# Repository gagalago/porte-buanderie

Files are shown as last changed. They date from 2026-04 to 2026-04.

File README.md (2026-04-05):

# Porte-etagere cuisine-buanderie

Conception d'une porte epaisse avec etageres integrees entre la cuisine et la buanderie,
montee sur un mecanisme 4-bar linkage (bras articules).

## Le probleme

L'ouverture fait 870mm de large. La porte fait 355mm d'epaisseur (pour les etageres).
La diagonale de la porte (940mm) depasse l'ouverture de 70mm, ce qui empeche un pivot
classique de fonctionner : le coin de la porte heurte le mur en pivotant.

## La solution

Un mecanisme a **4 barres articulees** (4-bar linkage) avec :
- 2 bras rigides reliant le mur droit (cote charnieres) a la porte
- 2 pattes qui sortent de la face arriere (buanderie) de la porte
- Le mecanisme combine translation + rotation, evitant la collision diagonale

La porte est **trapezoidale** (plus etroite cote buanderie) et encadree par des
**cadres de 25mm** de chaque cote, ce qui reduit les dimensions effectives.

## Dimensions cles

| Element | Valeur |
|---|---|
| Ouverture | 870mm |
| Mur gauche (trailing) | 355mm d'epaisseur |
| Mur droit (charnieres) | 425mm d'epaisseur |
| Espace derriere mur droit | 380mm (frigo juste derriere) |
| Marche cuisine-buanderie | 190mm |
| Hauteur porte | ~2040mm |

## Solution retenue

| Parametre | Valeur |
|---|---|
| Porte (cote cuisine) | 820 x 355mm |
| Forme | Trapeze, taper 60mm chaque coin buanderie |
| Face buanderie (etageres) | 700mm |
| Cadres | 25mm chaque cote (symetrique) |
| Pivot A (mur) | x=1238, y=428 |
| Pivot B (mur) | x=1188, y=532 |
| Patte a | 95mm, a x=563 sur la porte |
| Patte b | 188mm, a x=743 sur la porte |
| Bras 1 | 675mm |
| Bras 2 | 446mm |
| Rotation | ~91 degres |
| Clearance | ~14-24mm (selon resolution de simulation) |

## Structure du projet

```
porte-buanderie/
  calculs/
    optimisation_documentee.py  # Script principal: parametres + optimiseur
    animate_resultat.py         # Generation d'animation GIF (matplotlib)
    requirements.txt            # numpy, scipy, matplotlib, svgwrite, Pillow
  dessins/
    generate_plans.py           # Generation de plans SVG cotes
  freecad/
    porte_animable.py           # Genere un FCStd avec 21 positions
    live_animation.py           # Animation live via socket FreeCAD (WIP)
  exports/
    RESULTAT_animation.gif      # Animation du mecanisme
    plan_vue_dessus.svg         # Plan cote (vue de dessus)
    plan_porte_detail.svg       # Detail porte + etageres
    porte_animable.FCStd        # Modele 3D FreeCAD (21 positions groupees)
    frames_resultat/            # Frames PNG de l'animation
```

## Lancer l'optimisation

```bash
cd porte-buanderie
python3 -m venv .venv && source .venv/bin/activate
pip install -r calculs/requirements.txt
python3 calculs/optimisation_documentee.py
```

Modifier les parametres en haut de `optimisation_documentee.py` puis relancer.

## Generer l'animation GIF

Apres optimisation, mettre a jour les parametres dans `animate_resultat.py` puis :
```bash
python3 calculs/animate_resultat.py
# -> exports/RESULTAT_animation.gif
```

## Systeme de coordonnees

Vue de dessus, oriente comme depuis la cuisine :
- **X** : gauche (0) a droite (870)
- **Y** : cuisine (0) vers buanderie (positif)
- Mur gauche = cote trailing (x < 0), 355mm d'epaisseur
- Mur droit = cote charnieres (x > 870), 425mm d'epaisseur

## Prochaines etapes

- [ ] Valider les mesures sur place
- [ ] Animation FreeCAD live (socket server crash a resoudre)
- [ ] Plans techniques detailles des charnieres
- [ ] Choix materiaux (porte, bras, axes, roulements)
- [ ] Conception des roulettes (arc au sol buanderie)
- [ ] Prototype carton echelle 1:1
- [ ] Construction

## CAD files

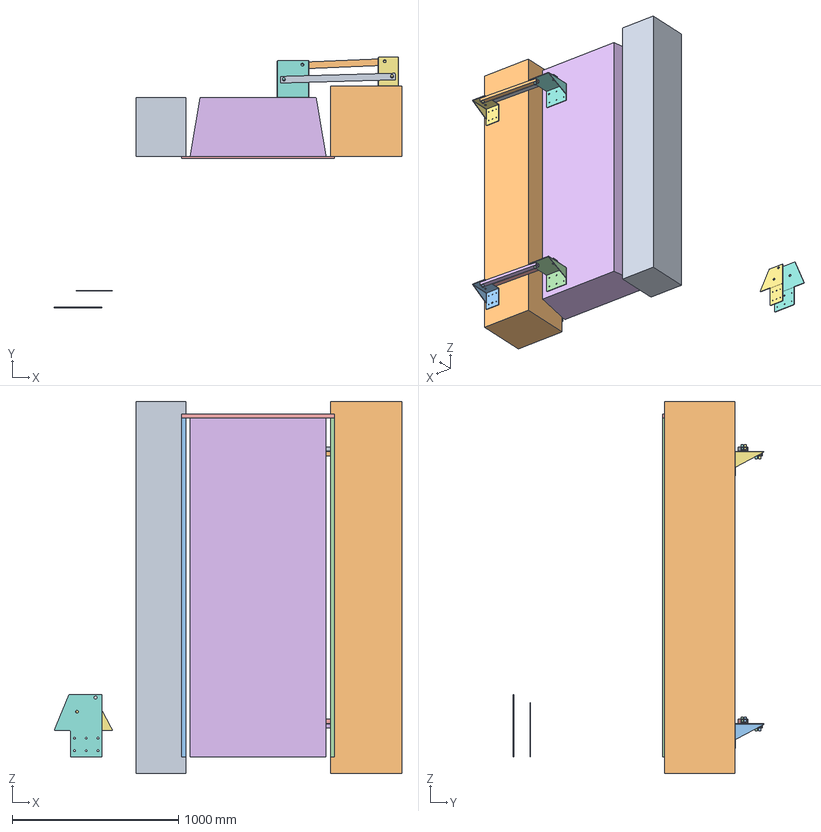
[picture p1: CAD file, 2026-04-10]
exports/assembly_porte.FCStd
2092.6 x 1509.1 x 2240.0 mm
MurGauche
MurDroit
CadreGauche
CadreDroit
CadreHaut
Porte
PlatMur_H
PlatPorte_H
Bras1_H
Bras2_H
PlatMur_B
PlatPorte_B
Bras1_B
Bras2_B
Patron_Plan_Patron_Murale
Patron_Plan_Patron_Porte

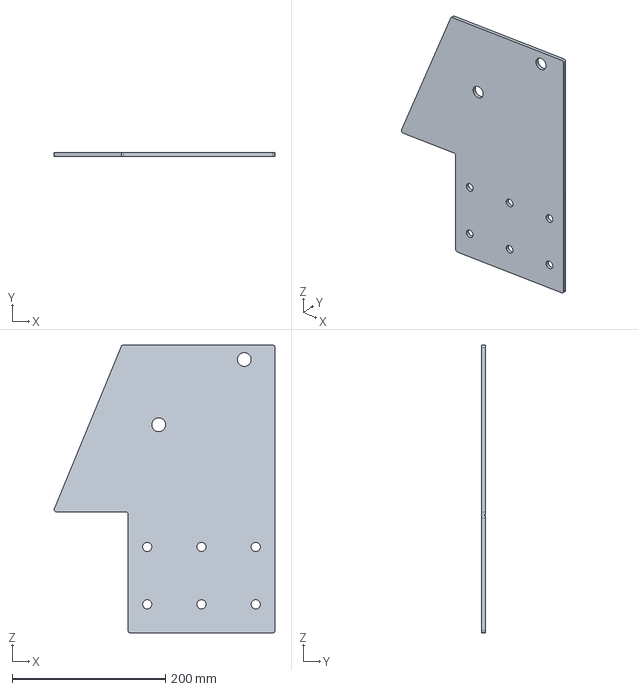
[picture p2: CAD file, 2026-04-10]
exports/patron_laser_porte.step
288.5 x 5.00 x 376.4 mm

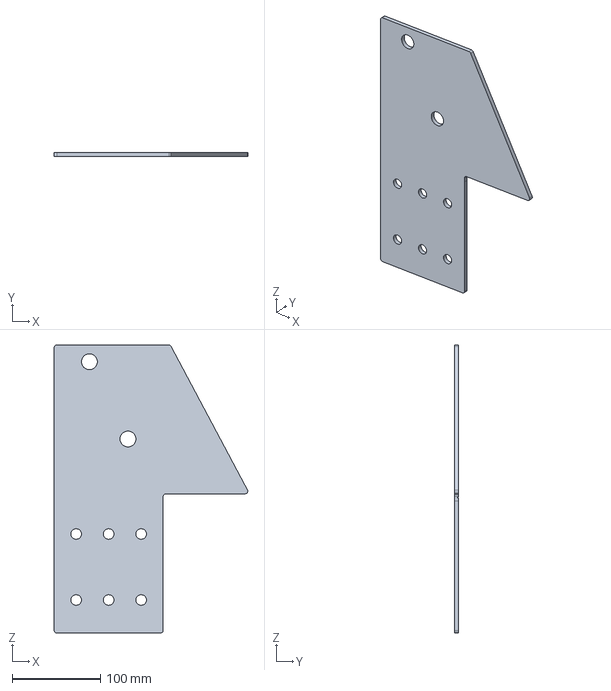
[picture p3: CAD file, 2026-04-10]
exports/patron_laser_murale.step
220.0 x 5.00 x 327.3 mm

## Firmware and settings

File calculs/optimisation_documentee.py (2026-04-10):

#!/usr/bin/env python3
"""
=============================================================================
OPTIMISATION D'UN MECANISME 4-BAR LINKAGE POUR PORTE EPAISSE
=============================================================================

PROBLEME:
    Une porte epaisse (355mm) doit pivoter dans une ouverture de 870mm.
    La diagonale de la porte (940mm) depasse l'ouverture de 70mm.
    Un pivot unique ne fonctionne pas: le coin de la porte heurte le mur.

SOLUTION:
    Un mecanisme a 4 barres (4-bar linkage) avec 2 bras articules qui
    relient le mur a la porte. Ce mecanisme combine translation et rotation,
    permettant a la porte de se decaler lateralement pendant qu'elle pivote.

=============================================================================
VUE DE DESSUS (plan) - Systeme de coordonnees
=============================================================================

    Vu depuis au-dessus, oriente comme quand on regarde depuis la cuisine:
    - X va de gauche (0) a droite (870)
    - Y va de la cuisine (0) vers la buanderie (positif)

    Y (vers buanderie)
    ^
    |
    |   Buanderie (y > 355 cote gauche, y > 425 cote droit)
    |
    +------  MUR GAUCHE  ---  OUVERTURE  ---  MUR DROIT  ------+
    |  (x < 0)           (x: 0 a 870)        (x > 870)        |
    |  (y: 0-355)                             (y: 0-425)       |
    +--- y = 0 (face cuisine) ---------------------------------+-------> X
    |
    |   Cuisine (y < 0)

    Mur GAUCHE (x < 0) : cote trailing (oppose aux charnieres), epaisseur 355mm
    Mur DROIT (x > 870) : cote charnieres, epaisseur 425mm
    Espace derriere le mur droit : 380mm dans la buanderie (x > 870, y > 425)

    Porte fermee:
        C1 = (CADRE_TRAILING, 0)     coin gauche, face cuisine (trailing)
        C2 = (CADRE_TRAILING+TAPER, DT)  coin gauche, face buanderie
        C3 = (OW-CADRE_HINGE-TAPER, DT)  coin droit, face buanderie
        C4 = (OW-CADRE_HINGE, 0)    coin droit, face cuisine (charnieres)

=============================================================================
LE MECANISME 4-BAR LINKAGE
=============================================================================

    2 pivots FIXES sur le mur (cote buanderie du mur droit):
        A = (Ax, Ay)    pivot fixe haut
        B = (Bx, By)    pivot fixe bas

    2 pivots MOBILES sur la face arriere de la porte (y = DT en coords locales):
        a = (ax_door, DT)    pivot porte, position x variable
        b = (bx_door, DT)    pivot porte, position x variable

    2 BRAS rigides:
        Bras 1: relie A a 'a' (longueur L1 = distance(A, a_ferme))
        Bras 2: relie B a 'b' (longueur L2 = distance(B, b_ferme))

    Schema (porte fermee, vue de dessus):

        Buanderie
                    A ----bras1---- a          b ----bras2---- B
                    (mur)           |__________|               (mur)
                                    |  PORTE   |
                                    |  (face   |
                                    | arriere) |
                                    C2---------C3
                                    |          |
                                    |          |
                                    C1---------C4
        Cuisine

    Quand le bras 1 tourne autour de A, il tire le point 'a' sur la porte.
    Le bras 2 contraint le point 'b'. La porte (corps rigide) suit le
    mouvement impose par les deux bras, se translatent ET pivotant.

=============================================================================
PARAMETRES FIXES (geometrie de la piece)
=============================================================================
"""

import numpy as np
from scipy.optimize import differential_evolution

# --- Dimensions de la piece (mesurees, en mm) ---
OW = 870          # Largeur de l'ouverture entre cuisine et buanderie
LWD = 355         # Epaisseur du mur GAUCHE (x < 0, cote trailing)
RWD = 425         # Epaisseur du mur DROIT (x > 870, cote charnieres)
SBR = 380         # Espace disponible derriere le mur droit (dans la buanderie)

# --- Dimensions de la porte (en mm) ---
DT = 355          # Epaisseur de la porte (= epaisseur mur gauche)
CADRE_HINGE = 25  # Cadre cote charnieres (droit)
CADRE_TRAILING = 25  # Cadre cote trailing (gauche)
DW = OW - CADRE_HINGE - CADRE_TRAILING  # = 750mm, largeur porte cote cuisine
CADRE = CADRE_HINGE + CADRE_TRAILING  # = 120mm total

# --- Forme trapeze de la porte (en mm) ---
# La porte peut etre un trapeze: pleine largeur cote cuisine, retreciee cote buanderie.
# On peut retrecir les DEUX coins buanderie independamment.
#
# TAPER_TRAILING = retrecissement du coin C3 (gauche-buanderie, cote trailing)
# TAPER_HINGE    = retrecissement du coin C2 (droit-buanderie, cote charnieres)
#
# 0 = pas de retrecissement de ce coin (angle droit)
# ex: TAPER_TRAILING=60 et TAPER_HINGE=30 donne:
#
#   Vue de dessus:
#
#      C2──────────────C3          y = DT (face buanderie, retreciee)
#      /                \          C2 est a x = TAPER_HINGE
#     /                  \         C3 est a x = DW - TAPER_TRAILING
#    /      PORTE         \
#   C1─────────────────────C4      y = 0 (face cuisine, pleine largeur)
#   x=0                  x=DW
#
# Cela reduit le cercle circonscrit a la porte (= le vrai "probleme diagonal")
# Un rectangle DW x DT a un cercle de rayon sqrt(DW²+DT²)/2
# Un trapeze a un cercle plus petit car les coins buanderie sont rentres.
#
TAPER_TRAILING = 60   # retrecissement coin C3 (gauche-buanderie)
TAPER_HINGE = 60      # retrecissement coin C2 (droit-buanderie)

# --- Modifications acceptees sur les murs ---
EXTRA_BACK = 0    # Pas d'espace supplementaire (frigo juste derriere)
EFF_BACK = SBR + EXTRA_BACK  # = 380mm, espace effectif derriere

# --- Parametres de simulation ---
N_STEPS = 50     # Nombre de pas de simulation (plus = plus precis mais plus lent)

"""
=============================================================================
PARAMETRES A OPTIMISER (6 variables)
=============================================================================

Ce sont les positions des 4 pivots du mecanisme:

1. Ax : position X du pivot fixe A sur le mur
         CONTRAINTE: doit etre SUR le mur droit, face buanderie
         Plage: de -380 (fond de l'espace derriere) a +30 (dans l'ouverture)

2. Ay : position Y du pivot fixe A sur le mur
         CONTRAINTE: doit etre SUR le mur droit
         Plage: de 395 a 455 (autour de y=425, face buanderie du mur droit)

3. Bx : position X du pivot fixe B sur le mur
         CONTRAINTE: doit etre SUR le mur droit (face buanderie OU retour)
         Plage: de -30 a +30 (pres du coin de l'ouverture)

4. By : position Y du pivot fixe B sur le mur
         CONTRAINTE: doit etre SUR le mur droit
         Plage: de 0 a 455 (le long du retour ou de la face buanderie)

5. ax_door : position X du pivot 'a' sur/derriere la face arriere de la porte
         Plage: de TAPER_HINGE+20 a DW-TAPER_TRAILING-20

6. bx_door : position X du pivot 'b' sur/derriere la face arriere de la porte
         Plage: de TAPER_HINGE+20 a DW-TAPER_TRAILING-20

7. ay_door : position Y du pivot 'a' (profondeur derriere la porte)
         DT = sur la face arriere, DT+200 = 20cm dans la buanderie (patte)
         Plage: de DT a DT+200

8. by_door : position Y du pivot 'b' (profondeur derriere la porte)
         Plage: de DT a DT+200

9. sweep : fraction de pi que parcourt le bras 1 pendant l'ouverture
         0.4 = 72 degres, 0.8 = 144 degres, 1.0 = 180 degres
         Plage: de 0.3 a 1.2

Les LONGUEURS des bras ne sont PAS des variables:
    L1 = distance(A, a_en_position_fermee) -- calculee automatiquement
    L2 = distance(B, b_en_position_fermee) -- calculee automatiquement
"""

# --- Contrainte hardware: clearance pivot <-> surface ---
# Le pivot doit etre assez loin de la surface (mur ou porte) pour loger:
#   - La tole de la platine (fond plaque contre la surface)
#   - Le demi-tube du bras (le bras pivote autour de l'axe)
#   - Un jeu de fonctionnement
# Dimensions quincaillerie:
TOLE_PLATINE = 5     # epaisseur tole platine (mm)
TUBE_BRAS_W = 40     # largeur tube bras (mm) - c'est la dimension qui peut frotter
JEU_PIVOT = 5        # jeu de fonctionnement (mm)
MIN_PIVOT_CLEARANCE = TOLE_PLATINE + TUBE_BRAS_W / 2 + JEU_PIVOT  # = 30mm

# Bornes pour l'optimisation (9 variables)
# Mur droit (charnieres) est a x > OW (= x > 870)
# Les pivots mur sont sur la face buanderie du mur droit: x de OW a OW+SBR
# Les pivots porte sont entre C2.x et C3.x sur la face arriere
C2X = CADRE_TRAILING + TAPER_TRAILING        # x du coin C2
C3X = OW - CADRE_HINGE - TAPER_HINGE         # x du coin C3
BOUNDS = [
    (OW - 30, OW + SBR),                    # Ax: sur/pres du mur droit
    (RWD + MIN_PIVOT_CLEARANCE, RWD + 200),  # Ay: au moins 30mm de la face mur
    (OW - 30, OW + SBR),                    # Bx: sur/pres du mur droit
    (RWD + MIN_PIVOT_CLEARANCE, RWD + 200),  # By: au moins 30mm de la face mur
    (C2X + 10, C3X - 10),                   # ax_door: x entre C2 et C3
    (C2X + 10, C3X - 10),                   # bx_door: x entre C2 et C3
    (DT + MIN_PIVOT_CLEARANCE, DT + 200),    # ay_door: au moins 30mm de la face porte
    (DT + MIN_PIVOT_CLEARANCE, DT + 200),    # by_door: au moins 30mm de la face porte
    (0.3, 1.2),                          # sweep: fraction de pi pour rotation bras 1
]


def coins_porte():
    """Les 4 coins de la porte en coordonnees monde (porte fermee).
    X inversee: gauche=trailing (x petit), droit=charnieres (x grand).
    La porte occupe x de CADRE_TRAILING a OW-CADRE_HINGE."""
    x_left = CADRE_TRAILING                     # bord gauche (trailing)
    x_right = OW - CADRE_HINGE                  # bord droit (charnieres)
    return np.array([
        [x_left, 0],                            # C1: gauche-cuisine (trailing)
        [x_left + TAPER_TRAILING, DT],           # C2: gauche-buanderie (retreci)
        [x_right - TAPER_HINGE, DT],             # C3: droit-buanderie (retreci)
        [x_right, 0],                            # C4: droit-cuisine (charnieres)
    ], dtype=float)


def points_contour(n_par_arete=10):
    """Points repartis sur le contour de la porte (pour verifier les collisions)."""
    coins = coins_porte()
    pts = []
    for i in range(4):
        for t in np.linspace(0, 1, n_par_arete, endpoint=False):
            pts.append(coins[i] * (1 - t) + coins[(i + 1) % 4] * t)
    return np.array(pts)


def transformer(pts, tx, ty, cos_a, sin_a):
    """Applique rotation + translation aux points.
    pts: (N,2) points en coords locales porte
    tx, ty: translation
    cos_a, sin_a: cos et sin de l'angle de rotation
    Retourne: (N,2) points en coords monde
    """
    return np.column_stack([
        pts[:, 0] * cos_a - pts[:, 1] * sin_a + tx,
        pts[:, 0] * sin_a + pts[:, 1] * cos_a + ty,
    ])


def verifier_collisions(pts_monde):
    """
    Calcule la clearance (distance aux murs) pour chaque point.

    Retourne un array de distances:
        > 0 : le point est dans l'espace libre (OK)
        < 0 : le point est DANS un mur (COLLISION)
        = 0 : le point touche un mur

    Les murs verifies (axe X inverse: gauche=0, droit=870):
        1. Mur gauche (trailing): x > 0 requis si y < LWD (355mm)
        2. Mur droit (charnieres): x < OW requis si y < RWD (425mm)
        3. Limite arriere mur droit: x < OW + EFF_BACK
        4. Sol cuisine: y > -2 requis (la porte peut affleurer a y=0)
    """
    x, y = pts_monde[:, 0], pts_monde[:, 1]
    clearance = np.full(len(x), 1e6)  # commence a +infini (tout OK)

    # 1. Mur gauche (trailing, x < 0): pour y < LWD, x doit etre > 0
    dans_zone_mur_gauche = y < LWD
    clearance[dans_zone_mur_gauche] = np.minimum(
        clearance[dans_zone_mur_gauche],
        x[dans_zone_mur_gauche]
    )

    # 2. Mur droit (charnieres, x > OW): pour y < RWD, x doit etre < OW
    dans_zone_mur_droit = y < RWD
    clearance = np.where(
        dans_zone_mur_droit,
        np.minimum(clearance, OW - x),
        clearance
    )

    # 3. Limite arriere mur droit: x < OW + EFF_BACK (espace derriere)
    np.minimum(clearance, OW + EFF_BACK - x, out=clearance)

    # 4. Sol cuisine: y doit etre > -2mm (tolerance pour affleurage)
    clearance = np.minimum(clearance, np.where(y < -2, y, 1e6))

    return clearance


def simuler_mecanisme(Ax, Ay, Bx, By, ax_door, bx_door, ay_door=DT, by_door=DT, sweep=0.8):
    """
    Simule le mouvement du 4-bar linkage.

    Retourne: (clearance_min, positions)
        clearance_min: la pire clearance sur tout le trajet (> 0 = OK)
        positions: liste de (tx, ty, angle, arm_ax, arm_ay, arm_bx, arm_by)
                   pour chaque pas de la simulation

    Les pivots porte sont a (ax_door, ay_door) et (bx_door, by_door) en coords
    locales de la porte. ay_door et by_door peuvent depasser DT (= pattes qui
    sortent de la face arriere de la porte dans la buanderie).
    """
    # Pivots sur la porte (coordonnees locales)
    # ay_door >= DT : sur la face arriere ou sur une patte derriere
    a_local = np.array([ax_door, ay_door])
    b_local = np.array([bx_door, by_door])

    # Bornes de la platine porte en coords locales (pour collision check)
    plat_margin = 40  # marge autour des pivots
    plat_x_min = min(ax_door, bx_door) - plat_margin
    plat_x_max = max(ax_door, bx_door) + plat_margin

    # Longueur du coupler (distance entre les 2 pivots porte)
    Lc = np.sqrt((bx_door - ax_door)**2 + (by_door - ay_door)**2)
    if Lc < 50:
        return -9999, None

    # Longueurs des bras (calculees a partir de la position fermee)
    # En position fermee, a_local en coords monde = (ax_door, ay_door)
    L1 = np.sqrt((Ax - ax_door)**2 + (Ay - ay_door)**2)
    L2 = np.sqrt((Bx - bx_door)**2 + (By - by_door)**2)
    if L1 < 30 or L2 < 30 or L1 > 800 or L2 > 800:
        return -9999, None

    # Direction du coupler en coords locales (a -> b)
    ang_local = np.arctan2(by_door - ay_door, bx_door - ax_door)

    # Angle initial du bras 1 (de A vers a_ferme)
    theta1_initial = np.arctan2(ay_door - Ay, ax_door - Ax)

    coins = coins_porte()
    points = points_contour(10)

    meilleur_resultat = -9999
    meilleures_positions = None

    # Essayer les 4 combinaisons branche/direction
    for branche in [0, 1]:
        for direction in [1, -1]:

            # --- Verification position fermee ---
            # A theta1_initial, la porte DOIT etre en position fermee
            theta1 = theta1_initial
            ax = Ax + L1 * np.cos(theta1)
            ay = Ay + L1 * np.sin(theta1)
            dx, dy = Bx - ax, By - ay
            d = np.sqrt(dx*dx + dy*dy)
            if d > Lc + L2 + 0.01 or d < abs(Lc - L2) - 0.01:
                continue

            # Trouver la position de b (intersection de 2 cercles)
            a_param = (Lc*Lc - L2*L2 + d*d) / (2*d)
            h = np.sqrt(max(0, Lc*Lc - a_param*a_param))
            mx = ax + a_param * dx / d
            my = ay + a_param * dy / d
            px, py = -dy / d * h, dx / d * h
            if branche == 0:
                bx, by = mx + px, my + py
            else:
                bx, by = mx - px, my - py

            # Calculer l'angle et la position de la porte
            angle_monde = np.arctan2(by - ay, bx - ax)
            angle_porte = angle_monde - ang_local
            co, si = np.cos(angle_porte), np.sin(angle_porte)
            tx = ax - (a_local[0]*co - a_local[1]*si)
            ty = ay - (a_local[0]*si + a_local[1]*co)

            # Verifier que c'est bien la position fermee: tx~0, ty~0, angle~0
            angle_mod = angle_porte % (2 * np.pi)
            if angle_mod > np.pi:
                angle_mod -= 2 * np.pi
            if (abs(tx) > 5 or abs(ty) > 5 or
                    (abs(angle_mod) > 0.1 and
                     abs(angle_mod - 2*np.pi) > 0.1 and
                     abs(angle_mod + 2*np.pi) > 0.1)):
                continue  # Ce n'est PAS la position fermee -> ignorer

            # --- Simulation du mouvement ---
            positions = []
            clearance_min = 1e6
            ok = True

            for i in range(N_STEPS):
                fraction = i / (N_STEPS - 1)  # 0.0 a 1.0
                theta1 = theta1_initial + direction * fraction * np.pi * sweep

                # Position du pivot 'a' sur le cercle de A
                ax = Ax + L1 * np.cos(theta1)
                ay = Ay + L1 * np.sin(theta1)

                # Trouver 'b' : intersection cercle(a, Lc) et cercle(B, L2)
                dx, dy = Bx - ax, By - ay
                d = np.sqrt(dx*dx + dy*dy)
                if d > Lc + L2 + 0.01 or d < abs(Lc - L2) - 0.01 or d < 1e-10:
                    ok = False
                    break

                a_param = (Lc*Lc - L2*L2 + d*d) / (2*d)
                h = np.sqrt(max(0, Lc*Lc - a_param*a_param))
                mx = ax + a_param * dx / d
                my = ay + a_param * dy / d
                px, py = -dy / d * h, dx / d * h
                if branche == 0:
                    bx, by = mx + px, my + py
                else:
                    bx, by = mx - px, my - py

                # Angle et position de la porte
                angle_monde = np.arctan2(by - ay, bx - ax)
                angle_porte = angle_monde - ang_local
                co, si = np.cos(angle_porte), np.sin(angle_porte)
                tx = ax - (a_local[0]*co - a_local[1]*si)
                ty = ay - (a_local[0]*si + a_local[1]*co)

                # Sauvegarder la position
                positions.append((tx, ty, angle_porte, ax, ay, bx, by))

                # Verifier les collisions (sauf step 0 = position fermee)
                if i > 0:
                    # 1. Porte vs murs
                    pts_monde = transformer(points, tx, ty, co, si)
                    cl = np.min(verifier_collisions(pts_monde))
                    clearance_min = min(clearance_min, cl)

                    # 2. Bras vs murs lateraux (pas la limite arriere)
                    # Les bras sont des tubes fins a Z=200 ou Z=1840, ils passent
                    # au-dessus/dessous du frigo derriere le mur.
                    # On verifie seulement: x > 0 (mur gauche) et x < OW si y < RWD (mur droit)
                    ARM_EXT = 20  # depassement tube au-dela des pivots
                    for (px_s, py_s, px_e, py_e) in [(Ax, Ay, ax, ay), (Bx, By, bx, by)]:
                        bdx = px_e - px_s; bdy = py_e - py_s
                        bl = np.sqrt(bdx*bdx + bdy*bdy)
                        if bl > 1:
                            bnx, bny = -bdy/bl, bdx/bl
                            hw = TUBE_BRAS_W / 2
                            ext = ARM_EXT / bl  # fraction de depassement
                            for t_frac in [-ext, 0.0, 0.25, 0.5, 0.75, 1.0, 1.0+ext]:
                                cx = px_s + t_frac * bdx
                                cy = py_s + t_frac * bdy
                                for side in [-hw, 0, hw]:
                                    bpx = cx + side * bnx
                                    bpy = cy + side * bny
                                    # Mur gauche: x > 0 si y < LWD
                                    if bpy < LWD:
                                        clearance_min = min(clearance_min, bpx)
                                    # Mur droit: x < OW si y < RWD
                                    if bpy < RWD:
                                        clearance_min = min(clearance_min, OW - bpx)
                                    # PAS de verif limite arriere pour les bras

                    # 3. Platine porte vs murs LATERAUX seulement
                    # La platine est fine (5mm tole), elle passe au-dessus du frigo
                    # comme les bras. Seule la porte (355mm) bloque l'espace arriere.
                    plat_pts_local = np.array([
                        [plat_x_min, DT], [plat_x_max, DT],
                        [plat_x_min, ay_door], [plat_x_max, ay_door],
                        [plat_x_min, by_door], [plat_x_max, by_door],
                        [ax_door, ay_door], [bx_door, by_door],
                    ])
                    plat_pts_monde = transformer(plat_pts_local, tx, ty, co, si)
                    plat_x = plat_pts_monde[:, 0]
                    plat_y = plat_pts_monde[:, 1]
                    # Mur gauche
                    mask_g = plat_y < LWD
                    if np.any(mask_g):
                        clearance_min = min(clearance_min, np.min(plat_x[mask_g]))
                    # Mur droit (retour dans l'ouverture)
                    mask_d = plat_y < RWD
                    if np.any(mask_d):
                        clearance_min = min(clearance_min, np.min(OW - plat_x[mask_d]))

            if not ok:
                continue

            # --- Verification position ouverte ---
            tx_final, ty_final, angle_final = positions[-1][:3]
            co, si = np.cos(angle_final), np.sin(angle_final)
            coins_ouverts = transformer(coins, tx_final, ty_final, co, si)
            x_max = np.max(coins_ouverts[:, 0])
            x_min = np.min(coins_ouverts[:, 0])

            # La porte doit etre derriere le mur droit (x > OW)
            if x_min < OW - 5:
                clearance_min = min(clearance_min, x_min - OW)
            # Et dans l'espace disponible (x < OW + EFF_BACK)
            if x_max > OW + EFF_BACK - 5:
                clearance_min = min(clearance_min, OW + EFF_BACK - x_max)
            # Et avoir tourne d'au moins 65 degres (objectif 75°)
            if abs(angle_final) < np.radians(65):
                clearance_min = min(clearance_min,
                                    -(75 - np.degrees(abs(angle_final))) * 2)

            if clearance_min > meilleur_resultat:
                meilleur_resultat = clearance_min
                meilleures_positions = positions

    return meilleur_resultat, meilleures_positions
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

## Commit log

2026-04-05 Initial commit: mecanisme 4-bar linkage porte-etagere
    Optimisation d'un mecanisme a 4 barres pour ouvrir une porte epaisse
    (355mm, contient des etageres) dans une ouverture de 870mm.
    Contenu:
    - Optimiseur (differential evolution) avec contraintes hardware
    - Animation 2D (matplotlib/GIF) et 3D (FreeCAD Assembly)
    - Plans de fabrication SVG cotes (platines pliees, bras, axes)
    - Design des charnieres: platines tole 5mm pliee (2 plis, 1 soudure),
    bras = tubes 40x25x3 perces, boulons D16
    Resultat: clearance 24mm, rotation 90deg, bras 584mm et 425mm.
    [assembly_porte.FCStd]
2026-04-05 Platines combinees A+B et a+b + re-optimisation clearance hardware
    - Contrainte MIN_PIVOT_CLEARANCE=30mm dans l'optimiseur (tole+demi-tube+jeu)
    - Re-optimisation: pivot A passe de 3mm a 46mm du mur, clearance 24mm
    - Platines combinees: 1 seule piece pour 2 pivots (fond+plat+cote)
    - Pivot A/a boulonne par-dessus (bras au-dessus du plat)
    - Pivot B/b boulonne par-dessous (bras en-dessous)
    - Toutes platines au meme Z, separation bras = 30mm
    - Bras simplifies: tubes 40x25x3 perces D18 (pas de plats d'extremite)
    - Plans SVG refaits: patron deplie + profil plie pour chaque platine
    - Boulons-pivots integres dans les platines (plus d'objets axes separes)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
    [assembly_porte.FCStd]
2026-04-05 Platines: geometrie physiquement correcte (pliable)
    - Plat au sommet du fond (pli 1 au bord superieur, pas au milieu)
    - Cote (raidisseur) au bord du plat (pli 2), descend vers le fond
    - Cote du bon cote: mural a droite (loin des bras), porte a gauche
    - Soudure cote<->fond ferme la structure
    - Parametre cote_side pour choisir le cote du raidisseur
    [assembly_porte.FCStd]
2026-04-05 Double mecanisme (haut+bas) + TechDraw 2 pages
    - 2 mecanismes identiques a Z=1840mm (haut) et Z=200mm (bas)
    - Fonction create_mechanism() factorisee, appelee 2x
    - Animation synchronisee des 2 mecanismes (4 bras + 2 platines porte)
    - TechDraw: page A3 assembly (vue face + dessus) + page A4 detail platine
    - Templates ISO corrigees
    [assembly_porte.FCStd]
2026-04-05 TechDraw: mise a plat des platines (patrons deplies)
    - Fonction make_patron_plat(): deplie les 3 faces a plat avec bend allowance
    (K=0.44, R=3mm, BA=8.2mm par pli)
    - Patron murale: ~138x427mm avec trous pivot + trous fixation + lignes pliage
    - Patron porte: ~182x453mm idem
    - Page TechDraw "Plan_MiseAPlat" (A3) avec les 2 patrons vus de dessus
    - Patrons caches dans la vue 3D (visibles uniquement dans TechDraw)
    [assembly_porte.FCStd]
2026-04-05 TechDraw: cotes sur les patrons deplies
    Annotations sur la page Plan_MiseAPlat pour chaque patron:
    - Largeur totale et longueur totale du patron
    - Sections cotees: FOND (150mm), PLAT, COTE avec dimensions
    - Lignes de pliage marquees (pli 1 et pli 2, rayon R3)
    - Trous pivot D18 identifies (dessus/dessous)
    - Entraxe entre les 2 pivots
    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
    [assembly_porte.FCStd]
2026-04-08 TechDraw: patrons deplies sur pages separees (mur + porte)
    - Plan_Patron_Murale (A4 landscape): patron deplie platine murale
    - Plan_Patron_Porte (A4 landscape): patron deplie platine porte
    - Chaque page: vue de dessus du patron + cotes (sections, plis,
    trous pivot D18, entraxe, specs materiaux)
    - Remplace l'ancienne page unique surchargee
    - Fonction make_patron_page() factorisee
    [assembly_porte.FCStd]
2026-04-08 Script SM unfold pour console FreeCAD
    Script a executer dans la console Python de FreeCAD (GUI requis):
    exec(open('.../sm_unfold_platines.py').read())
    Cree les 2 platines via Sheet Metal workbench:
    - Base (fond) -> pli 1 -> plat -> pli 2 -> cote
    - Unfold automatique avec K-factor 0.44
    - Lignes de pliage en rouge
    - Trous pivot et fixation
    Genere exports/sm_platines_unfold.FCStd pour comparer
    avec les patrons TechDraw de assembly_porte.FCStd.
2026-04-08 TechDraw: mise a plat des platines (patrons deplies)
    - Patron en forme de L (correct): fond + plat + cote lateral
    Le cote se deplie depuis le BORD du plat, pas depuis le bout
    - Pli 1 horizontal (fond/plat), pli 2 vertical (plat/cote)
    - Cotes adaptees a la nouvelle geometrie en L
    - Vue de face (-Y) au lieu de vue de dessus
    [assembly_porte.FCStd]
2026-04-08 Annotations TechDraw lisibles + SM unfold corrige
    TechDraw patron pages:
    - Annotations repositionnees sans chevauchement
    - Fond/Plat/Cote labels au centre de leur section
    - Pivots et dims sur les marges droite/gauche
    - Specs condensees en une ligne en bas de page
    - Helper z_to_y() pour le mapping 3D->page
    SM unfold script:
    - Pli 2 cherche le bord LATERAL du plat (pas le bout)
    - Trous perces AVANT le depliage
    - Meilleure detection d'edges avec criteres flexibles
    - Debug: liste les edges si detection echoue
    [assembly_porte.FCStd]
2026-04-08 Fix annotations TechDraw + trous SM unfold
    TechDraw patrons:
    - Reduit a 4 annotations par page (titre, dims, trous, specs)
    - Dims et trous dans la marge droite, bien espaces
    - Plus de chevauchement
    - Trous coupes dans la shape directement (pas Part::Feature dans Body)
    - Piece percee visible (SM brut cache), patron deplie a cote
    - Return 3 valeurs (body, deplie, perce)
    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
    [assembly_porte.FCStd]
2026-04-08 TechDraw patron: vue reduite + titre seul (pas de chevauchement)
    - Vue patron a scale 0.45 decalee a gauche (X=90)
    - Supprime toutes les annotations sauf le titre
    - Les cotes detaillees restent dans les plans SVG
    - SM unfold: trous coupes dans la shape (pas Part::Feature)
    [assembly_porte.FCStd]
2026-04-08 TechDraw: patrons A3 + cotes auto (fond, plat, trous)
    - Pages patron passees en A3 Landscape (420x297) au lieu d'A4
    - Patron a scale 0.55 centree avec espace autour
    - Cotes automatiques via detection d'edges:
    - Largeur fond (w)
    - Hauteur fond (FOND_H)
    - Hauteur plat (plat_depth)
    - Diametre pivot (D18)
    - Diametre fixation (D12)
    - 5 cotes par page, positionnees autour du patron
    [assembly_porte.FCStd]
2026-04-08 TechDraw: cotes sur les patrons deplies
    - Fix edge indexing (1-based dans TechDraw, pas 0-based)
    - References2D + References3D pour cotes correctes
    - 5 cotes par patron: largeur fond, hauteur fond, hauteur plat,
    diametre pivot D18, diametre fixation D12
    - Pages A3 Landscape
    [assembly_porte.FCStd]
2026-04-10 Verification collisions complete: bras + platines + porte
    - Nouveau script verifier_collisions_complet.py (400 pas haute resolution)
    Verifie: porte vs murs, bras vs murs lateraux, platine porte vs murs lateraux
    - Optimiseur modifie: verifie bras et platine porte a chaque pas
    - Bras: check murs lateraux seulement (tubes fins, passent au-dessus du frigo)
    - Platine porte: idem (tole 5mm fine)
    - Porte: check complet (355mm epais, bloque l'espace arriere)
    - Re-optimisation avec verif complete:
    A=(1241,482) B=(1197,570) a=(590,464) b=(702,549)
    Clearance 23.2mm, rotation 89.3deg
    AUCUNE COLLISION sur porte + bras + platines
    - Tous les fichiers mis a jour avec les nouveaux parametres
    C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
    [assembly_porte.FCStd]
2026-04-10 Cadres: habillage decoratif cote cuisine (plinthes)
    Les cadres sont des plinthes sur la face cuisine des murs,
    autour de l'ouverture (pas dans l'ouverture):
    - CadreGauche: sur le mur gauche, x de -25 a 0, y de -12 a 0
    - CadreDroit: sur le mur droit, x de 870 a 895, y de -12 a 0
    - CadreHaut: traverse, toute la largeur, au-dessus de la porte
    Epaisseur 12mm, depassent vers la cuisine (y<0).
    [assembly_porte.FCStd]
2026-04-10 Bras rallonges +20mm de chaque cote des pivots
    - ARM_EXTEND=20mm: le tube depasse au-dela des trous pivot
    pour avoir de la matiere autour (pas de trou au bord)
    - Optimiseur et verificateur mis a jour pour checker le depassement
    - Re-optimisation: memes parametres, clearance 23.9mm
    - Verification complete: AUCUNE COLLISION (porte + bras + platines)
    [assembly_porte.FCStd]
2026-04-10 Platines: cote triangulaire + coins arrondis + export STEP laser
    Patron a plat redesigne pour decoupe laser:
    - Cote (raidisseur) TRIANGULAIRE au lieu de rectangulaire
    Moins de matiere, meme rigidite (gousset)
    - Coins exterieurs arrondis R3mm (securite + laser-friendly)
    - Contour 2D propre (polygone ferme extrude)
    Platine 3D pliee mise a jour avec cote triangulaire.
    Export STEP des patrons pour decoupe laser:
    - exports/patron_laser_murale.step
    - exports/patron_laser_porte.step
    FEM: necessite CalculiX (yay -S calculix-ccx) pour analyse
    de contraintes. A faire quand le solveur sera installe.
    [assembly_porte.FCStd, patron_laser_murale.step, patron_laser_porte.step]
2026-04-10 Source unique pour platines: patron et 3D depuis memes parametres
    Architecture refactoree:
    - platine_params(): calcule TOUTES les dimensions (source unique)
    - _platine_contour_2d(): contour du patron (utilise par les deux)
    - make_patron_plat(): patron a plat (laser/TechDraw)
    - make_platine_3d(): platine 3D pliee (assembly)
    Les deux derivent des memes parametres. Modifier une dimension
    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
    [assembly_porte.FCStd, patron_laser_murale.step, patron_laser_porte.step]
